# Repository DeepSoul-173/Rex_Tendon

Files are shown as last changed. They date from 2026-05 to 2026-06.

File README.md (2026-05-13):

# Rex Tendon
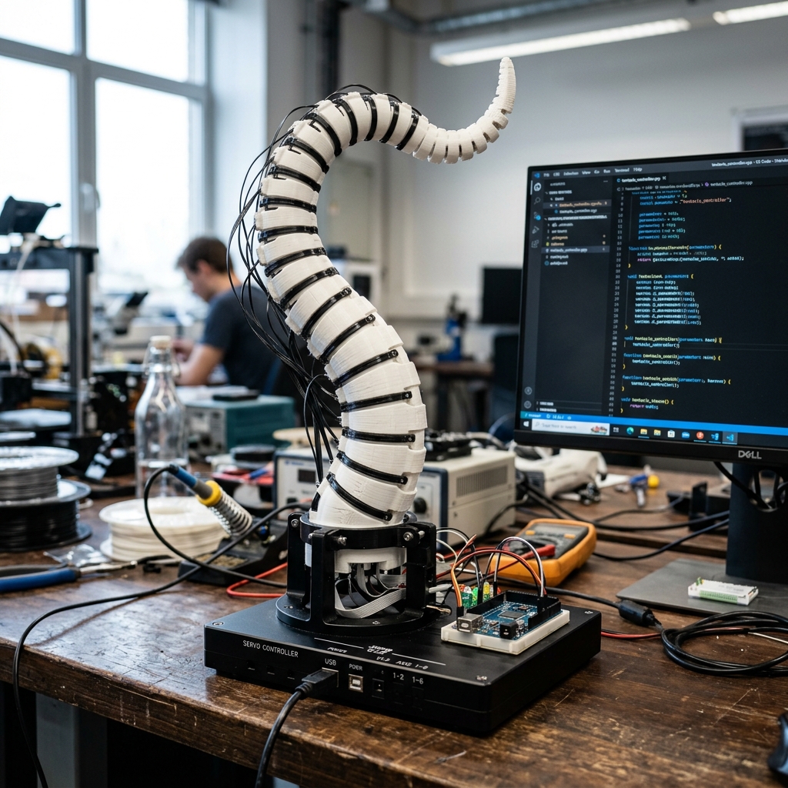
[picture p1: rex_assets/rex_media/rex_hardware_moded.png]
Rex Tendon Hardware


Rex Tendon is a soft-bodied tentacle robot using the [SpiRobs](https://arxiv.org/pdf/2303.09861) design, controlled through a mix of reinforcement learning and GPT-4o. Read the full blogpost [here](https://www.matthieulc.com/posts/rex-tendon/).

## Quick Start

### 1. Installation

First, ensure you have Python 3.10+ and [Poetry](https://python-poetry.org/docs/#installation) installed.

Clone the project repository and install the dependencies:
```bash
git clone https://github.com/DeepSoul-173/Rex_Tendon
cd rex-tendon
poetry install
```

Next, `lerobot` is a key dependency that needs to be installed from source:
```bash
git clone https://github.com/huggingface/lerobot.git
pip install -e ./lerobot
```

Finally, activate the virtual environment to run the subsequent commands:
```bash
eval "$(poetry env activate)"
```

### 2. Hardware Configuration

Find the USB port for the driver board using a script from `lerobot`:
```bash
python lerobot/scripts/find_motors_bus_port.py
```

Once you have the port, configure each motor (for IDs 1, 2, and 3), replacing `DRIVER_BOARD_USB_PORT` with the port you found:
```bash
python lerobot/scripts/configure_motor.py \
  --port DRIVER_BOARD_USB_PORT \
  --brand feetech \
  --model sts3215 \
  --baudrate 1000000 \
  --ID 1
```

### 3. Motor Calibration

Calibrate the motors by adjusting with the arrow keys until the tentacle tip is straight, then press Enter to save:
```bash
python -m rex_tendon calibrate --config rex_tendon/configs/default_hardware.yaml
```

### 4. Run the Orchestrator

Run the main orchestrator application, which integrates all system components:
```bash
python -m rex_tendon orchestrate \
  --config rex_tendon/configs/default_orchestrator.yaml \
  --hardware-config rex_tendon/configs/default_hardware.yaml \
  --perception-config rex_tendon/configs/default_perception.yaml \
  --control-config rex_tendon/configs/default_control.yaml
```

## Hardware Replication

For a full replication and setup of the robot, follow the steps in [ASSEMBLY.md](ASSEMBLY.md). All 3D printing assets are included in the repository. The total should cost less than 200$.

## Software Replication

### 1. Hardware Setup

Test motor connections:
```bash
python -m rex_tendon primitive "<yes>" --config rex_tendon/configs/default_hardware.yaml
```

Calibrate motors:
```bash
python -m rex_tendon calibrate --config rex_tendon/configs/default_hardware.yaml
```

### 2. Manual Control

Control with trackpad:
```bash
python -m rex_tendon trackpad --config rex_tendon/configs/default_hardware.yaml
```

Test idle motion with breathing pattern:
```bash
python -m rex_tendon idle --duration 10 \
  --hardware-config rex_tendon/configs/default_hardware.yaml \
  --control-config rex_tendon/configs/default_control.yaml
```

### 3. RL Pipeline

Generate MuJoCo XML model:
```bash
python -m rex_tendon generate-xml --output-path rex_assets/rex_simulation/tentacle.xml
```

Train RL model:
```bash
python -m rex_tendon rl train --config rex_tendon/configs/default_rl_training.yaml
```

Monitor with Tensorboard:
```bash
tensorboard --logdir=./
```

Evaluate RL model in simulation:
```bash
mjpython -m rex_tendon rl evaluate ./rex_results/ppo_tentacle_XXXXXXX/rex_models/best_model.zip --config rex_tendon/configs/default_rl_training.yaml --num-episodes 10 --render
```

### 4. Vision Pipeline

Record calibration images for stereo triangulation. Tune the pause interval to have time to change the pattern orientation:
```bash
python -m rex_tendon record stereo-calibration --num-pairs 20 --interval 3
```

Calculate the stereo triangulation calibration parameters using the images you just recorded by following the steps in the DeepLabCut notebook under `notebooks/3d_triangulation.ipynb`.

Record annotation videos. This command will record 6 pairs (one for each camera) of 10 second videos:
```bash
python -m rex_tendon record annotation --duration 60 --chunk-duration 10
```

Extract representative frames using k-means:
```bash
python -m rex_tendon extract-frames video.mp4 output_frames/ 100
```

I used [roboflow](https://roboflow.com/) to annotate these images, it has a great auto-label feature to avoid wasting time on high confidence images.

Then change `base_model` in the vision training config to point to the best model checkpoint and continue training on real images.

Evaluate trained model:
```bash
python -m rex_tendon vision evaluate model.pt dataset.yaml --config rex_tendon/configs/default_vision_training.yaml
```

Infer on single image:
```bash
python -m rex_tendon vision predict model.pt image.jpg --output prediction.jpg --confidence 0.5 --config rex_tendon/configs/default_vision_training.yaml
```

Debug stereo vision and triangulation:
```bash
python -m rex_tendon debug-perception --config rex_tendon/configs/default_perception.yaml
```

### 5. Full System

Run the closed loop RL model and vision model on the real robot:
```bash
python -m rex_tendon.control.closed_loop \
  --control-config rex_tendon/configs/default_control.yaml \
  --perception-config rex_tendon/configs/default_perception.yaml \
  --hardware-config rex_tendon/configs/default_hardware.yaml
```

Run the full orchestrator:
```bash
python -m rex_tendon orchestrate \
  --config rex_tendon/configs/default_orchestrator.yaml \
  --hardware-config rex_tendon/configs/default_hardware.yaml \
  --perception-config rex_tendon/configs/default_perception.yaml \
  --control-config rex_tendon/configs/default_control.yaml
```

## Known Issues

- Control can sometimes cause the motors to go into infinite rolling/unrolling for unknown reasons. What works for me in the situation is to reset by unrolling the cables to their maximum, and re-rolling them back. This sometimes requires opening up the robot to untangle wires. I haven't found the time to fix this, if you do, please open a PR!
- `orchestrator/orchestrator.py`, `control/closed_loop.py` and `control/idle.py` were heavily vibe-coded and have only been lightly refactored.
- Inference using `control/closed_loop.py` leads to a tracking offset on the Y axis as compared to simulation.

## Possible Extensions

- Increase robustness of GPT4o layer or train from scratch (e.g. [Moshi-like](https://kyutai.org/rex_assets/pdfs/Moshi.pdf))
- Give it a voice (but as non-human as possible!)
- Train more RL policies (e.g. grabbing and holding complex objects)
- Use direct drive motors to reduce noise
- Add more tentacles and make it crawl
- Ditch the 2D projection control to unlock more expressive policies

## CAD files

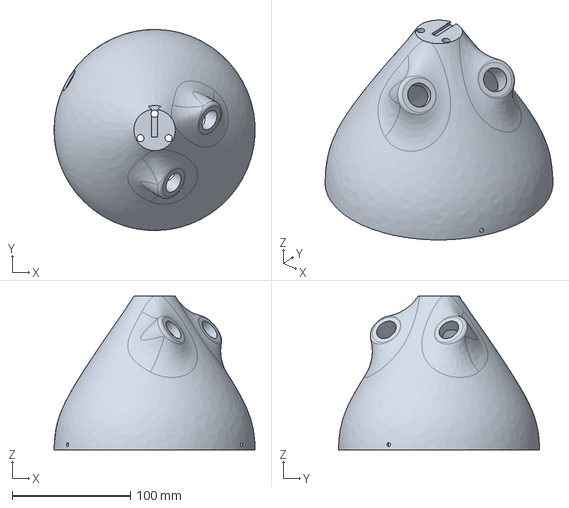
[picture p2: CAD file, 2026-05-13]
rex_assets/rex_hardware/printing/dome.step
169.9 x 169.9 x 130.0 mm

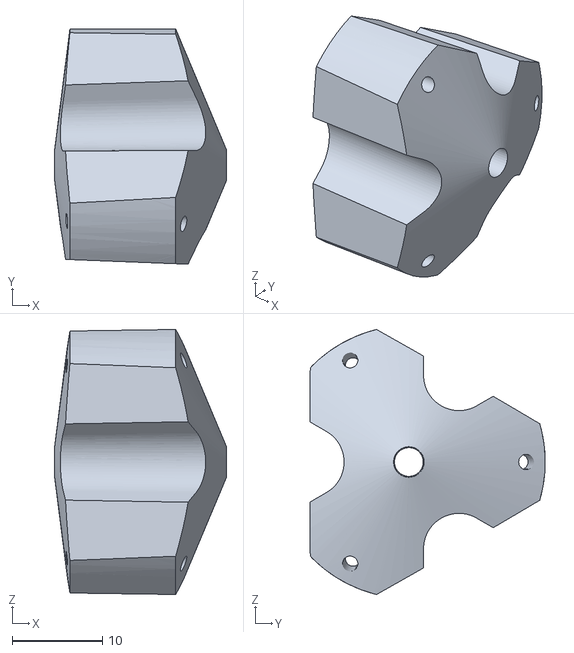
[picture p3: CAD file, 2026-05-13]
rex_assets/rex_simulation/mujoco_rex_assets/Part2.stl
19.1 x 26.1 x 29.3

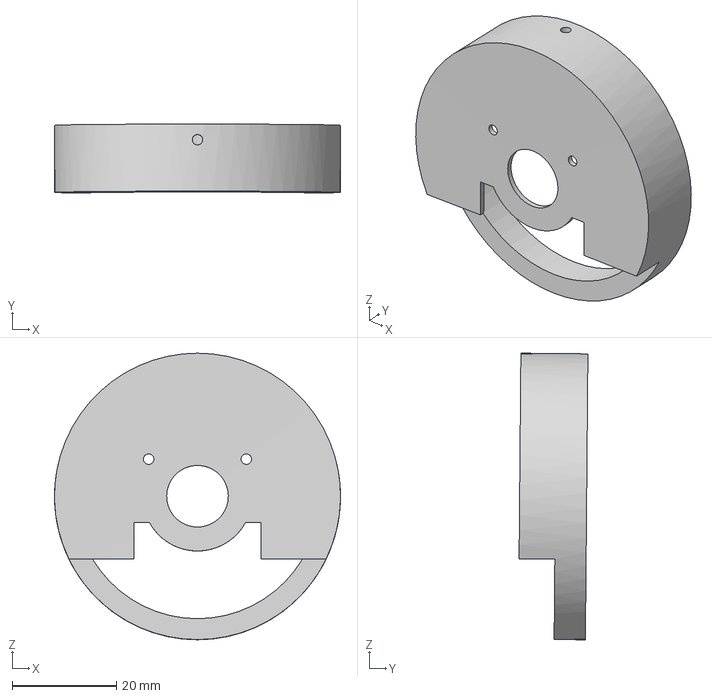
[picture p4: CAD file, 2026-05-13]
rex_assets/rex_hardware/printing/roller_cover.step
54.8 x 13.2 x 54.9 mm

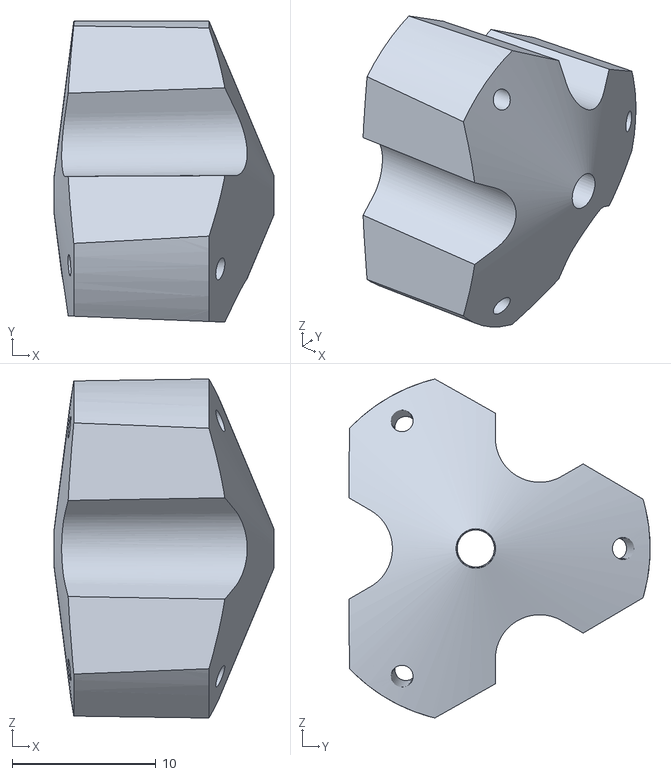
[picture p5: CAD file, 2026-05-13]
rex_assets/rex_simulation/mujoco_rex_assets/Part5.stl
15.3 x 20.9 x 23.6

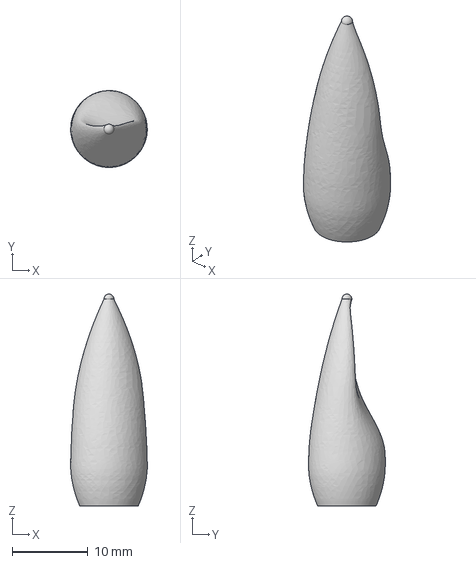
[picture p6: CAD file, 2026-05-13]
rex_assets/rex_hardware/printing/spike.step
10.1 x 10.1 x 27.9 mm

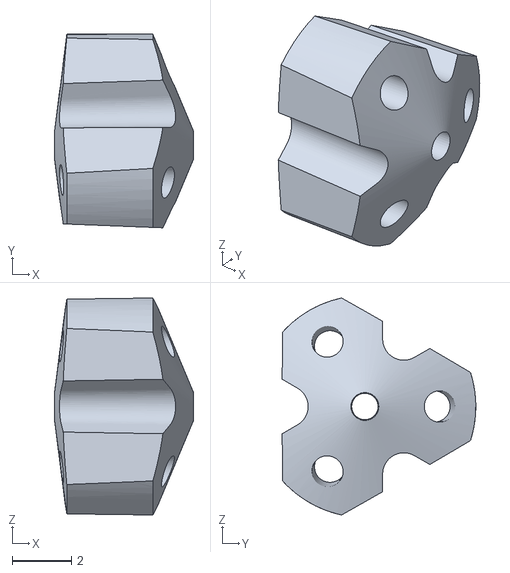
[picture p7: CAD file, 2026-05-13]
rex_assets/rex_simulation/mujoco_rex_assets/Part21.stl
4.70 x 6.55 x 7.33

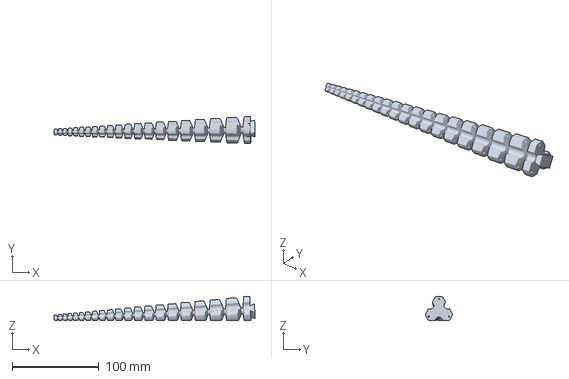
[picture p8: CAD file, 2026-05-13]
rex_assets/rex_hardware/printing/thick_spirobs.3mf
231.5 x 31.4 x 27.8 mm

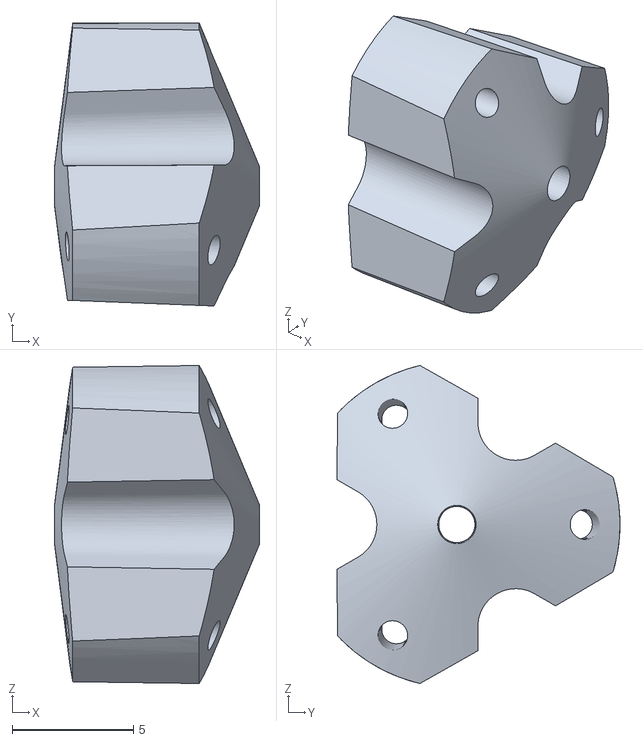
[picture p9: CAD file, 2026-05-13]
rex_assets/rex_simulation/mujoco_rex_assets/Part13.stl
8.49 x 11.7 x 13.1

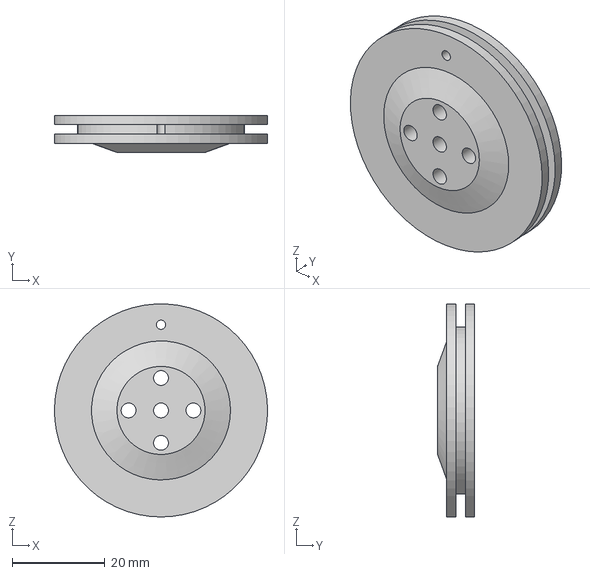
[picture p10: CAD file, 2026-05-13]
rex_assets/rex_hardware/printing/roller.step
46.0 x 8.00 x 46.0 mm

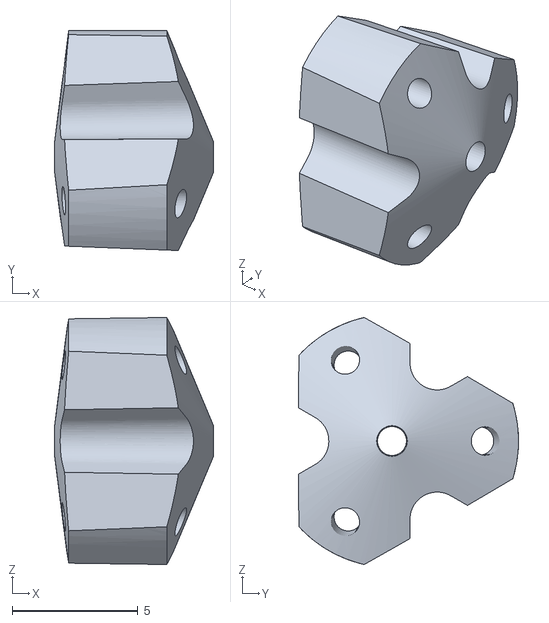
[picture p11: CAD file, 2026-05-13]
rex_assets/rex_simulation/mujoco_rex_assets/Part17.stl
6.32 x 8.74 x 9.81

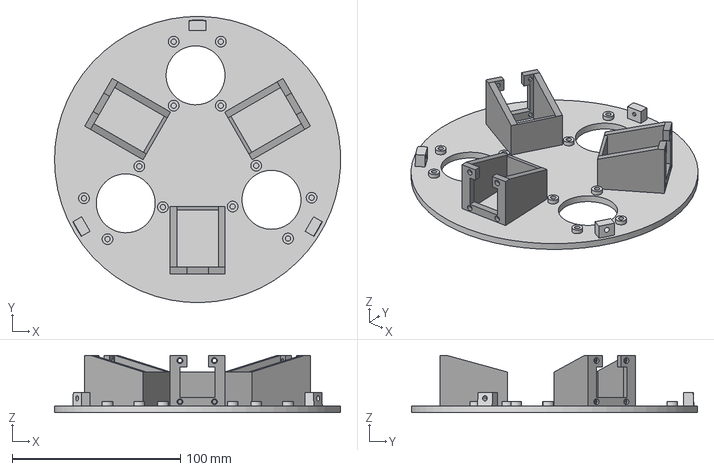
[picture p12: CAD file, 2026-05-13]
rex_assets/rex_hardware/printing/plate.step
169.9 x 169.9 x 34.0 mm

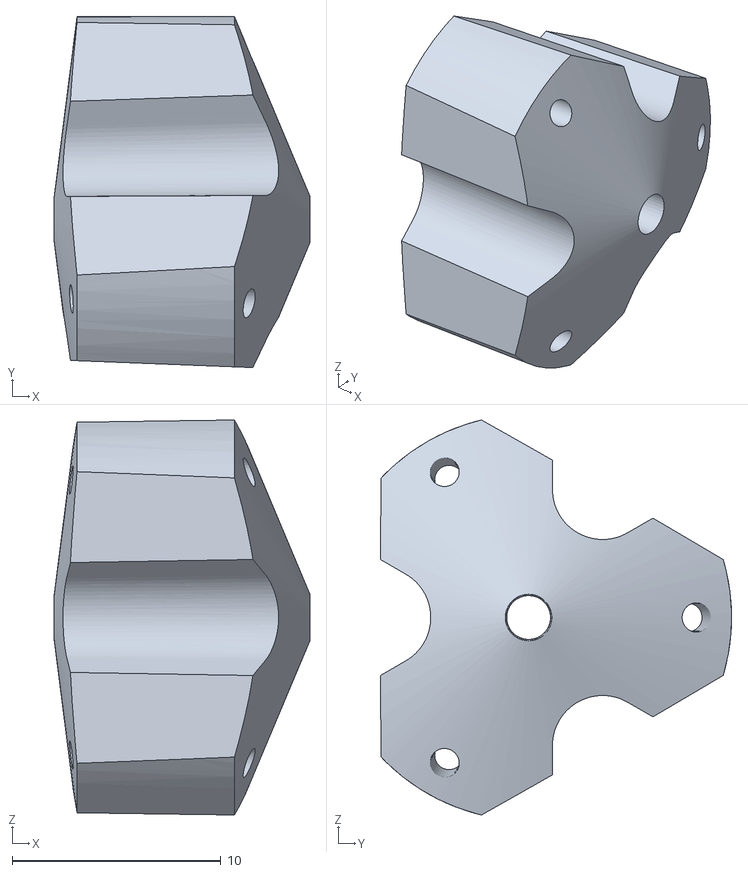
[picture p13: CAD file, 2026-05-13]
rex_assets/rex_simulation/mujoco_rex_assets/Part8.stl
12.3 x 16.8 x 18.9

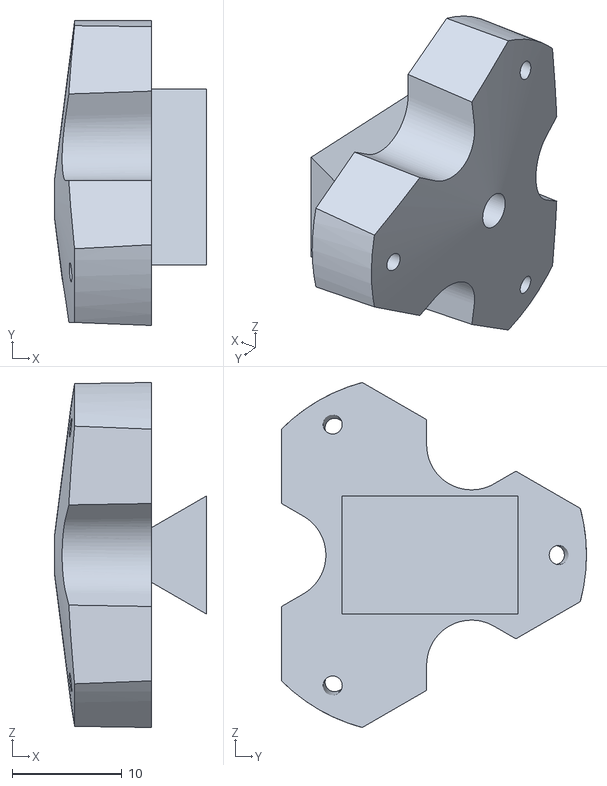
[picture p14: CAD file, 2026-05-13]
rex_assets/rex_simulation/mujoco_rex_assets/Part1.stl
13.9 x 27.8 x 31.4

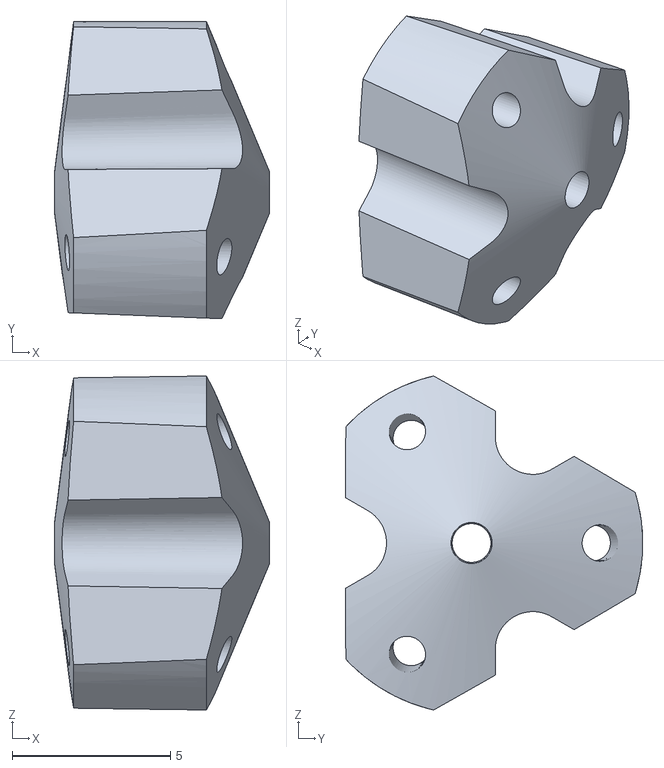
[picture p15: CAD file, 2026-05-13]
rex_assets/rex_simulation/mujoco_rex_assets/Part16.stl
6.80 x 9.40 x 10.6

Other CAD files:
rex_assets/rex_simulation/mujoco_rex_assets/Part9.stl
rex_assets/rex_simulation/mujoco_rex_assets/Part3.stl
rex_assets/rex_simulation/mujoco_rex_assets/Part11.stl
rex_assets/rex_simulation/mujoco_rex_assets/Part12.stl
rex_assets/rex_simulation/mujoco_rex_assets/Part10.stl
rex_assets/rex_simulation/mujoco_rex_assets/Part14.stl
rex_assets/rex_simulation/mujoco_rex_assets/Part15.stl
rex_assets/rex_simulation/mujoco_rex_assets/Part18.stl
rex_assets/rex_simulation/mujoco_rex_assets/Part19.stl
rex_assets/rex_simulation/mujoco_rex_assets/Part20.stl
rex_assets/rex_simulation/mujoco_rex_assets/Part4.stl
rex_assets/rex_simulation/mujoco_rex_assets/Part6.stl
rex_assets/rex_simulation/mujoco_rex_assets/Part7.stl

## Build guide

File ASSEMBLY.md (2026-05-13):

# Assembly

## Parts List

### Electronics
- **1x** Waveshare Serial Bus Servo Driver Board  
  [Amazon](https://www.amazon.fr/dp/B0CJ6TP3TP)

- **3x** Waveshare 20kg.cm Bus Servo Motors (includes mounting screws)
  [Amazon](https://www.amazon.fr/dp/B0CDC587BQ)

- **1x** 60W 12V 5A Power Supply  
  [Amazon](https://www.amazon.fr/dp/B001W3UYLY)

- **1x** USB-C to USB-C cable (for servo driver board)
- **1x** USB Micro to USB-C cable (for camera)

- **1x** Synchronous 3D Stereo USB Camera (3840×1080P, 4MP, 60fps, 130° FOV)  
  [AliExpress](https://www.aliexpress.com/item/1005006353765708.html)

> **Note:** If using a different camera, you may need to adapt the 3D printed parts and object detection model accordingly.

### Hardware
- **2x** M2×3×3 Heat Set Inserts  
  [Amazon](https://www.amazon.fr/dp/B0CS6XJSSL)

- **7x** M2.5×3.5×4 Heat Set Inserts  
  [Amazon](https://www.amazon.fr/dp/B0CS6YVJYD)

- **2x** M2 × 6mm Screws

- **2x** M2.5 × 10mm Screws

- **3x** M2.5 × 6mm Screws

- **0.5mm 21kg Fishing Wire** (we'll later cut 3x 80cm segments)

### 3D Printing Materials
- **eTPU-95A Filament** (for printing SpiRobs)  
  [eSUN 3D](https://esun3d.fr/products/esun-etpu-95a-gris-grey-1-75-mm-1-kg)

- **PLA Filament** (for rigid structural parts)

## Printing

### Dome - PLA
<div align="center">
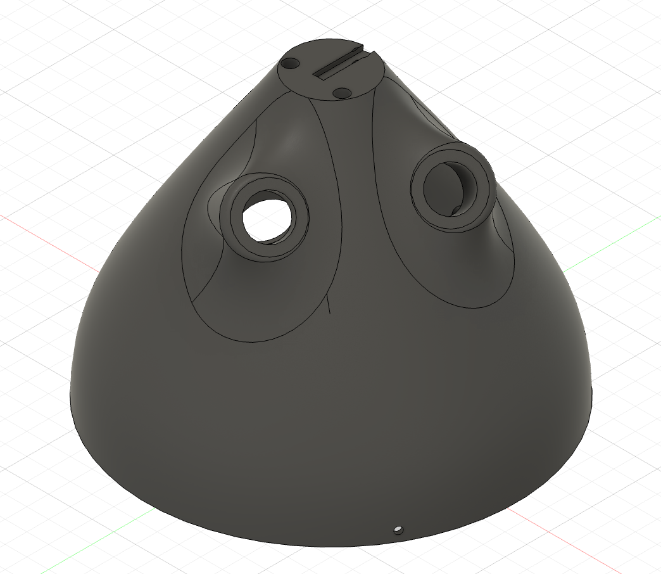
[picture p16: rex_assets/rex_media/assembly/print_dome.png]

</div>

[Download STEP file](rex_assets/rex_hardware/printing/dome.step)

### Plate - PLA
<div align="center">
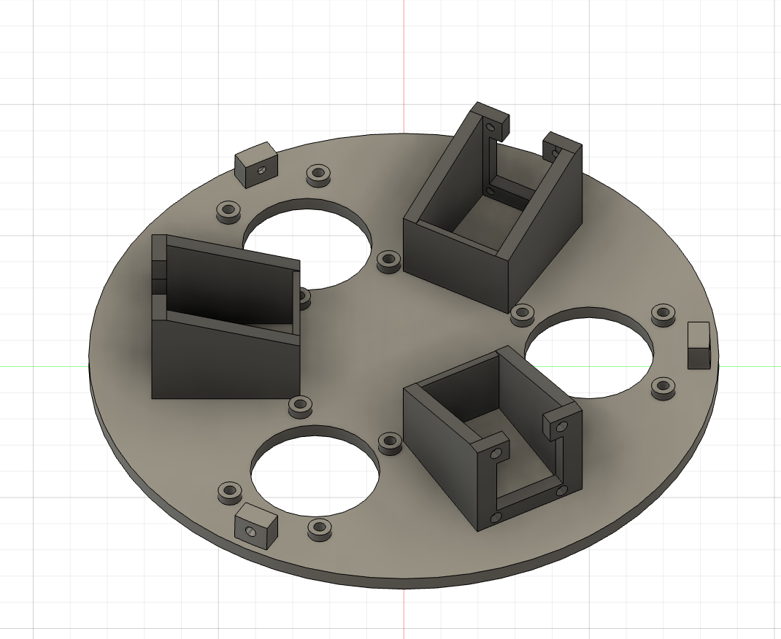
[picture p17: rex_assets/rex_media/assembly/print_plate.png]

</div>

[Download STEP file](rex_assets/rex_hardware/printing/plate.step)

### Roller Cover - PLA (3x)
<div align="center">
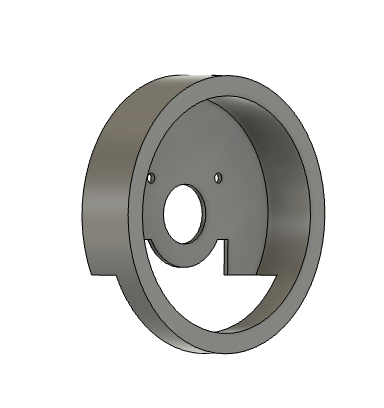
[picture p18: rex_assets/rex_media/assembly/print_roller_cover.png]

</div>

[Download STEP file](rex_assets/rex_hardware/printing/roller_cover.step)

### Roller - PLA (3x)
<div align="center">
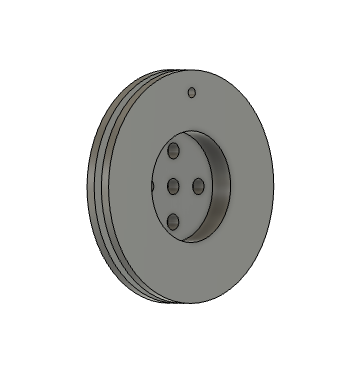
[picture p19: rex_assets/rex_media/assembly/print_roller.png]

</div>

[Download STEP file](rex_assets/rex_hardware/printing/roller.step)

### Spike - PLA
<div align="center">
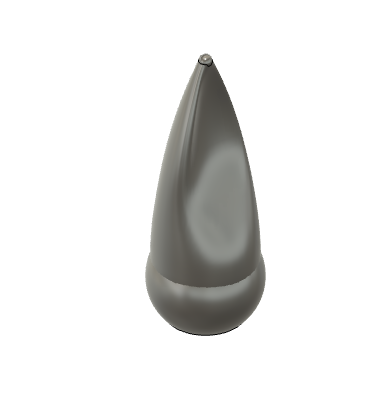
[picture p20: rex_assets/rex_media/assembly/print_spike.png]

</div>

[Download STEP file](rex_assets/rex_hardware/printing/spike.step)

### Thick SpiRobs - eTPU
<div align="center">
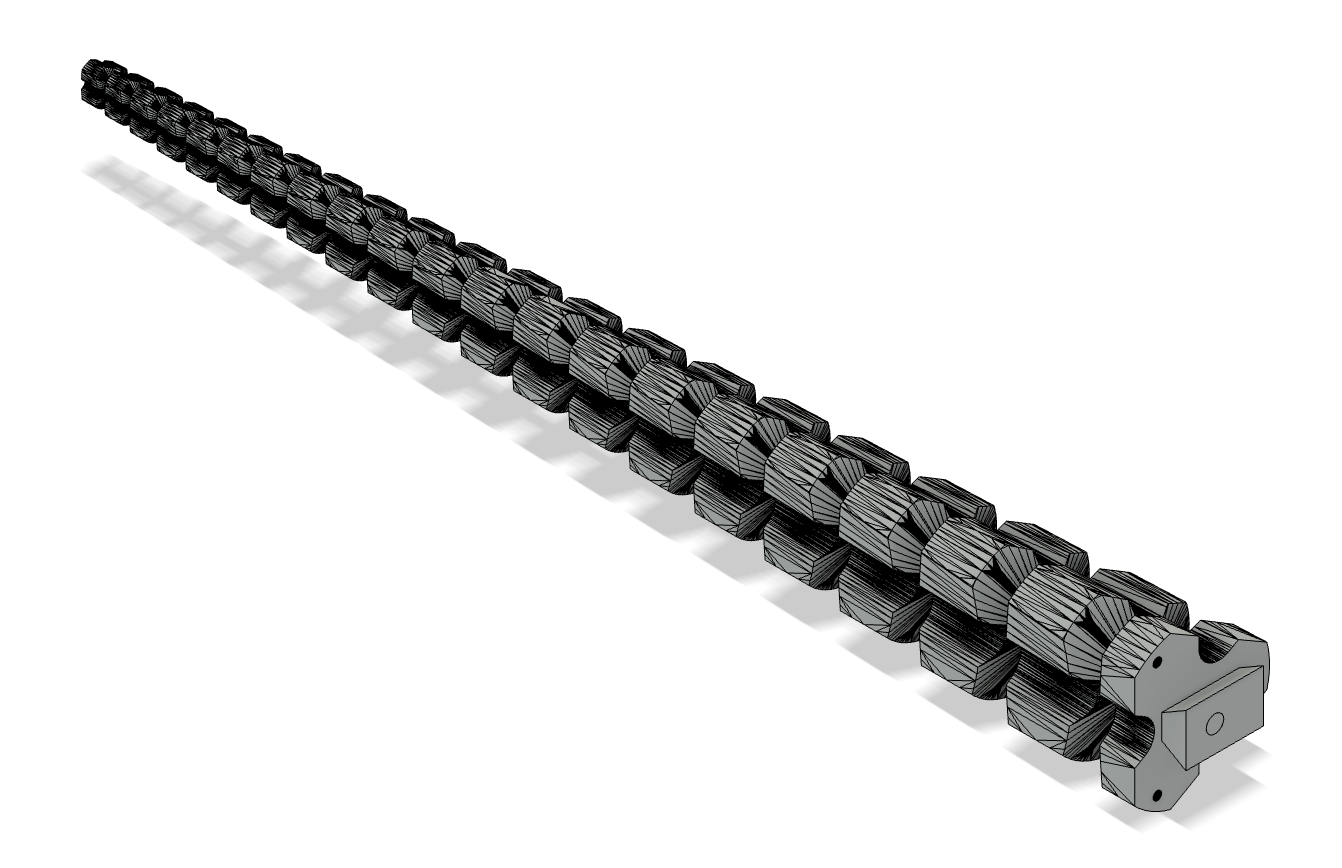
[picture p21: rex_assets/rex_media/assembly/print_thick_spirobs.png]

</div>

[Download 3MF file](rex_assets/rex_hardware/printing/thick_spirobs.3mf) | [Download STEP file](rex_assets/rex_hardware/printing/thick_spirobs.step)

> **Note:** This is a modified version of the 3-cable SpiRobs with a thicker spine for increased rigidity and stability.

## Assembly Instructions

### Plate Preparation and Servo Driver Board Installation

Install 4x M2.5 heat set inserts at either of the driver board mounting locations on the plate using a soldering iron.

<div align="center">
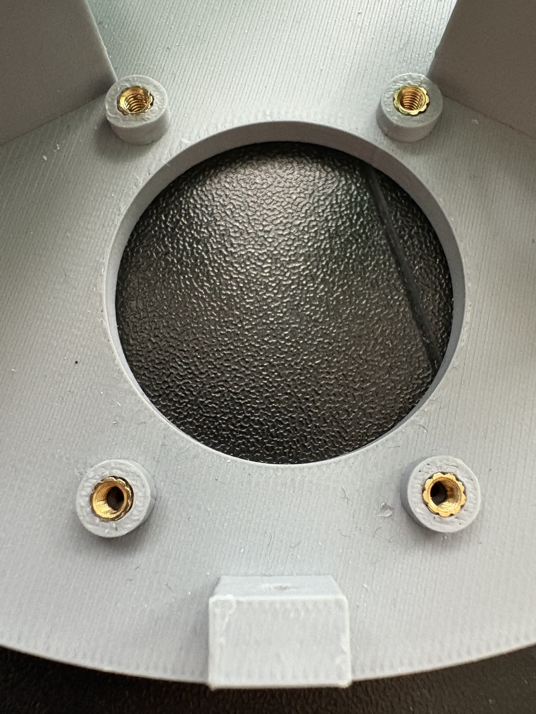
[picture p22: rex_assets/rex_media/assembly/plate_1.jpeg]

</div>

Install 3x M2.5 heat set inserts at the dome fastener locations using a soldering iron.

<div align="center">
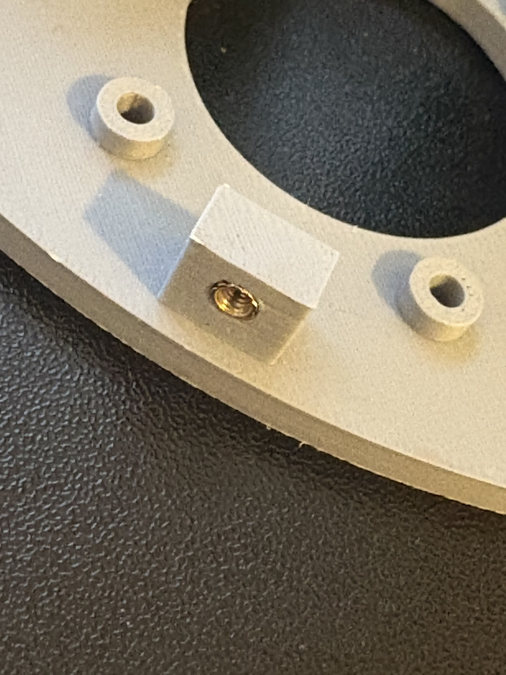
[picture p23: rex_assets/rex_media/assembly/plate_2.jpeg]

</div>

Mount the servo driver board to the plate using 2x M2.5 × 10mm screws (alternatively, use all four corner mounting holes). PCB standoffs can be used to elevate the driver board if desired.

<div align="center">
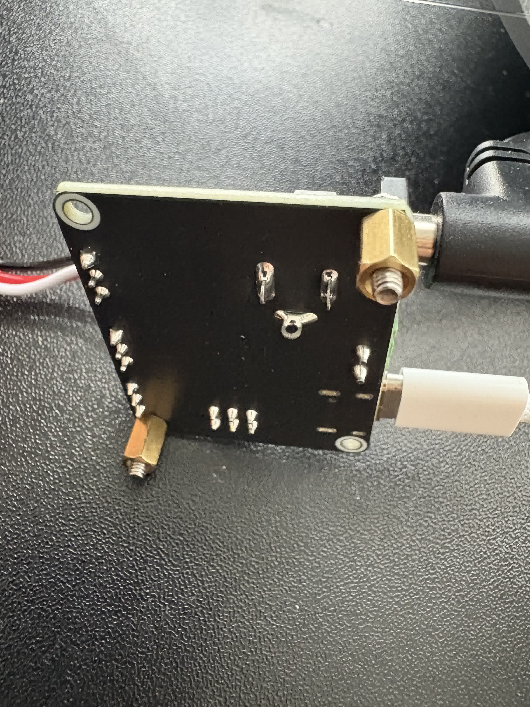
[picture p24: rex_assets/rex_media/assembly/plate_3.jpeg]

</div>

Secure the board to the plate at the previously installed insert locations.

<div align="center">
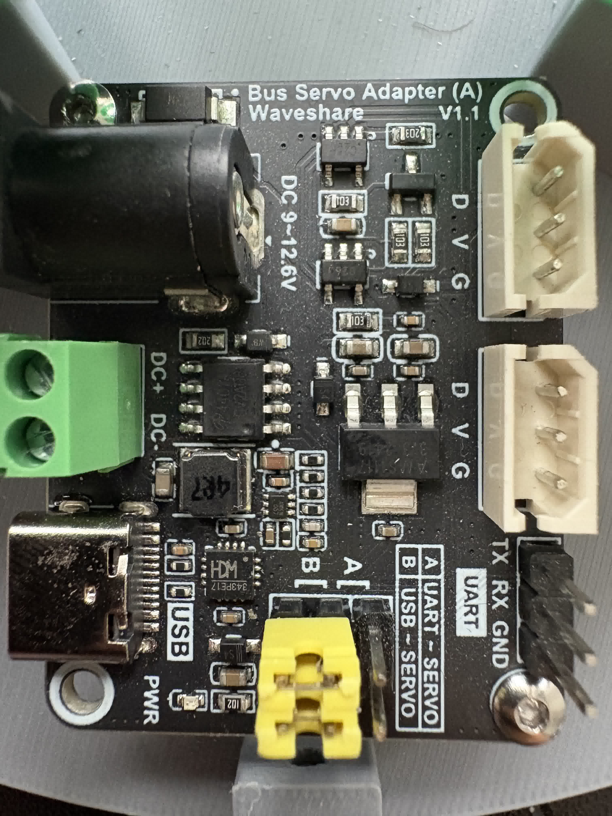
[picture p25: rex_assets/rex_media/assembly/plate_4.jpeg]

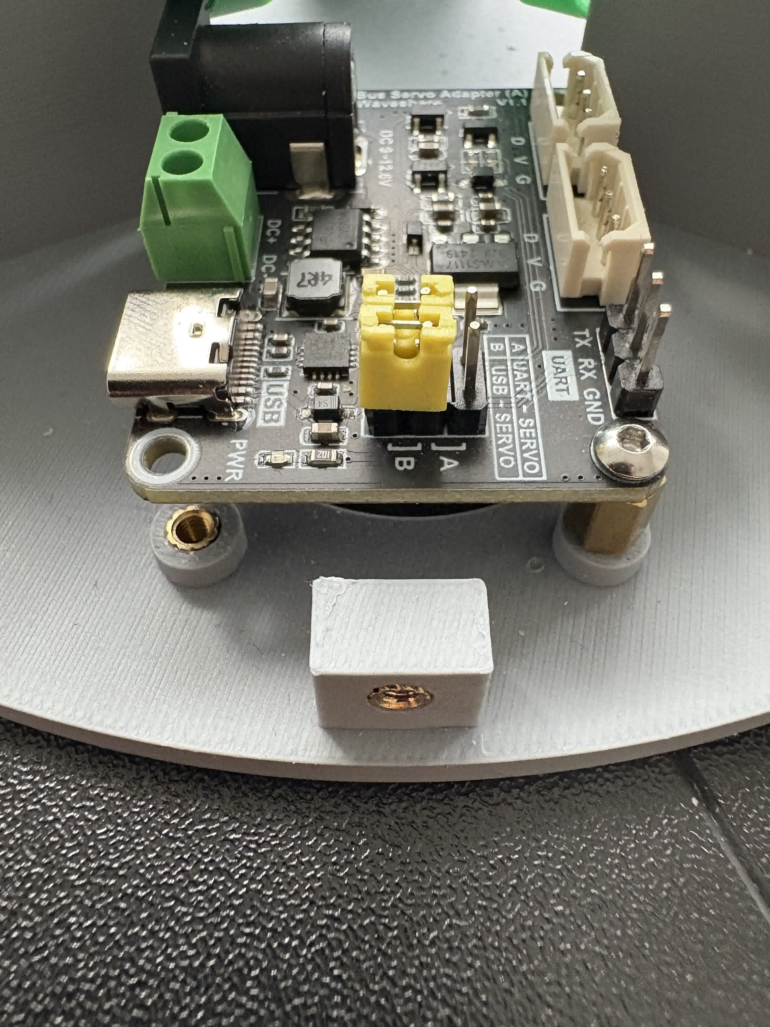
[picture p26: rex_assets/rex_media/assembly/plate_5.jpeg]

</div>

### Camera Mounting

Install 2x M2 heat set inserts at the camera fastener locations on the dome using a soldering iron.

<div align="center">
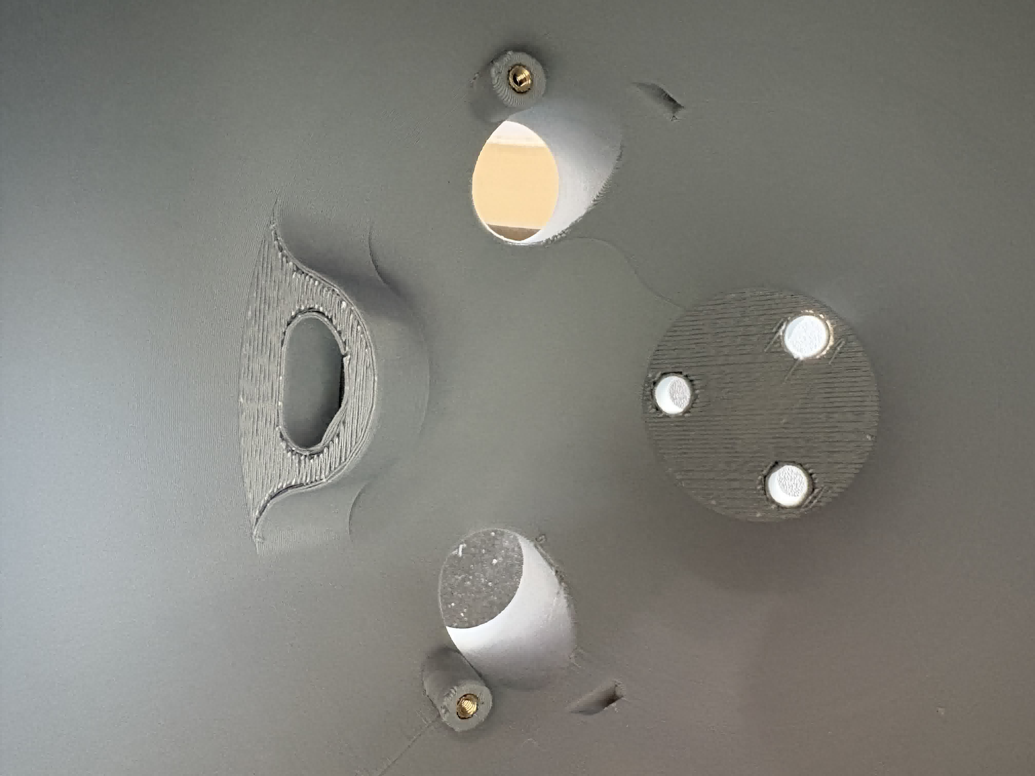
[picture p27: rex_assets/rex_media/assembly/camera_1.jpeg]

</div>

Position the camera in the mounting recesses within the dome and secure with 2x M2 × 6mm screws into the installed inserts.

<div align="center">
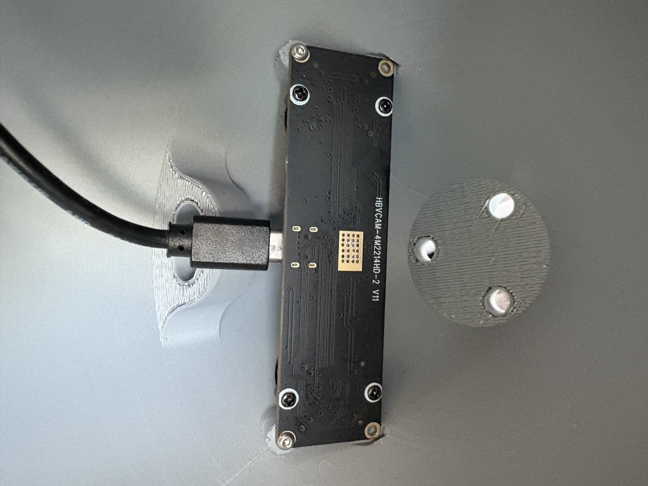
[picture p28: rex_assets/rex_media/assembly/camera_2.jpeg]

</div>

### Motor Assembly and Mounting

Remove the two top screws from each Waveshare motor and insert the motors into the roller covers.

<div align="center">
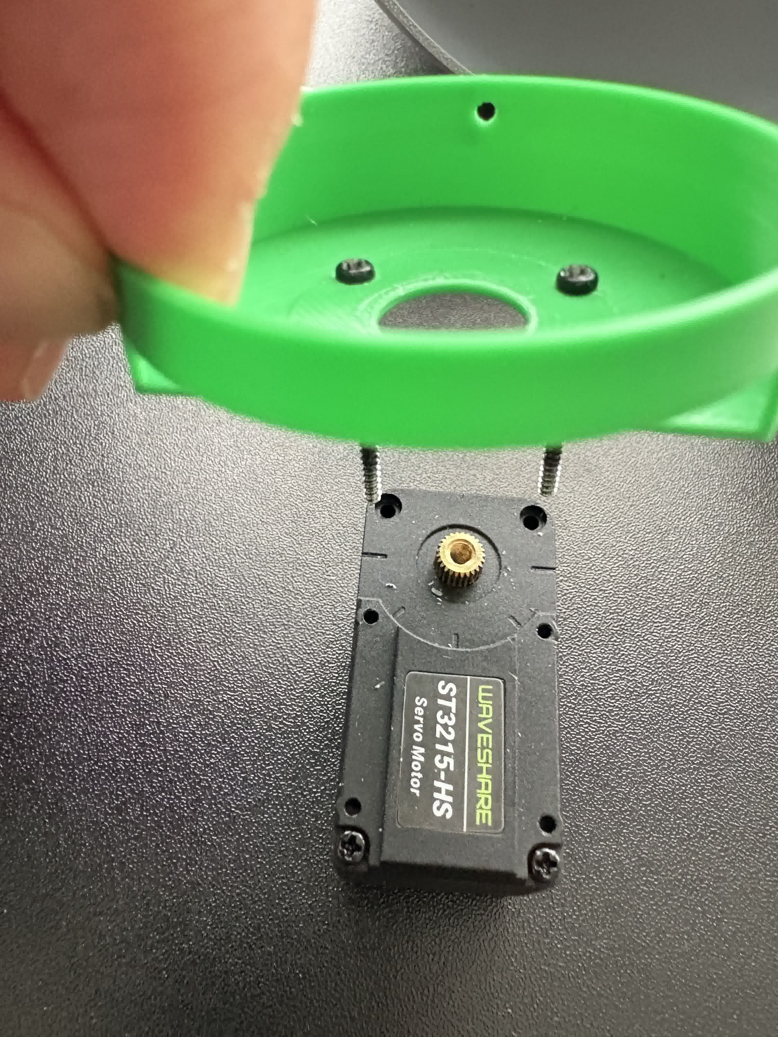
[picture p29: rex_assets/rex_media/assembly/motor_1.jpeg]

</div>

Reinstall the screws to secure the motors within the roller covers.

<div align="center">
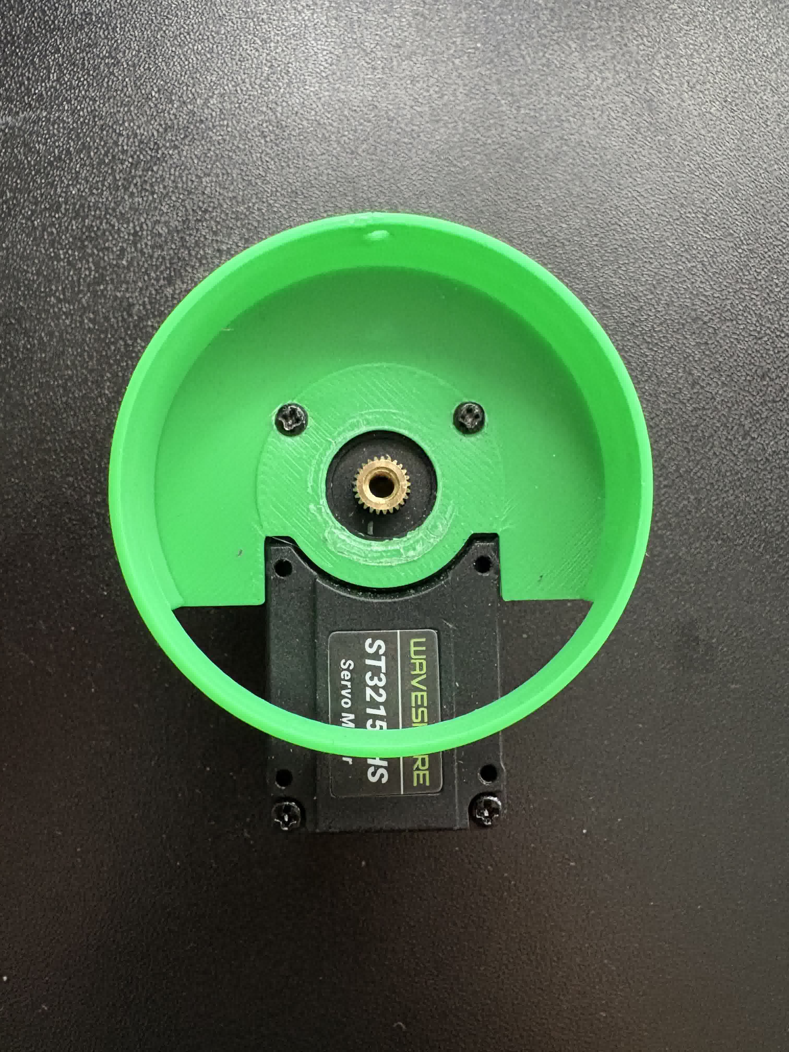
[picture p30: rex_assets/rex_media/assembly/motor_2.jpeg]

</div>

Attach the rollers to each motor assembly.

<div align="center">
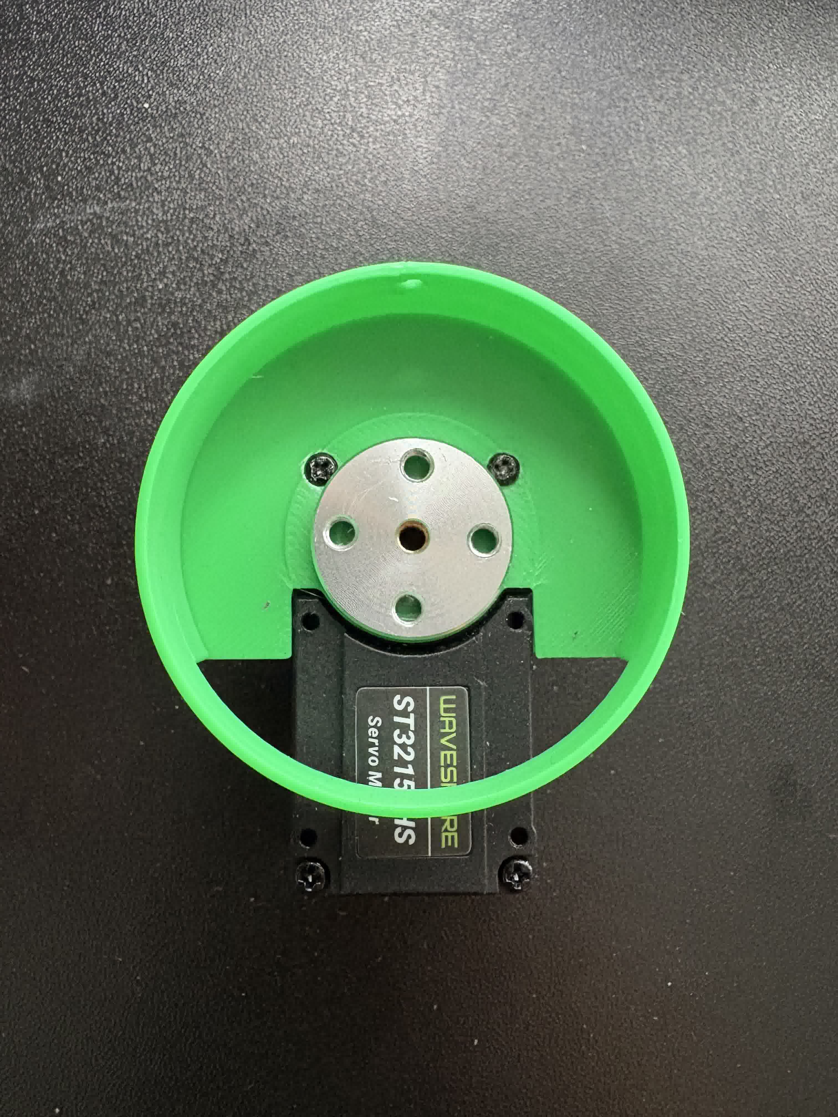
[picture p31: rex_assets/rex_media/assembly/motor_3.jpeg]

</div>

Repeat this procedure for the two other servo motors. Before proceeding, assign motor IDs according to the diagram below. Use stickers to identify each motor. For proper operation with the control software, each motor must be assigned the correct ID relative to the driver board position. The driver board should be positioned near the cable opening, opposite the camera where most operations will occur.

To assign motor IDs using the LeRobot codebase:

1. Connect each motor individually to the driver board
2. Connect the power cable to the driver board and USB-C cable to your computer
3. Find the USB port for the driver board:
```bash
git clone https://github.com/huggingface/lerobot.git
cd lerobot
python lerobot/scripts/find_motors_bus_port.py
```

4. Configure each motor ID (repeat for motors 1, 2, and 3):
```bash
python lerobot/scripts/configure_motor.py \
  --port DRIVER_BOARD_USB_PORT \
  --brand feetech \
  --model sts3215 \
  --baudrate 1000000 \
  --ID 1
```

Once configured, insert each motor into its designated slot on the plate.

<div align="center">
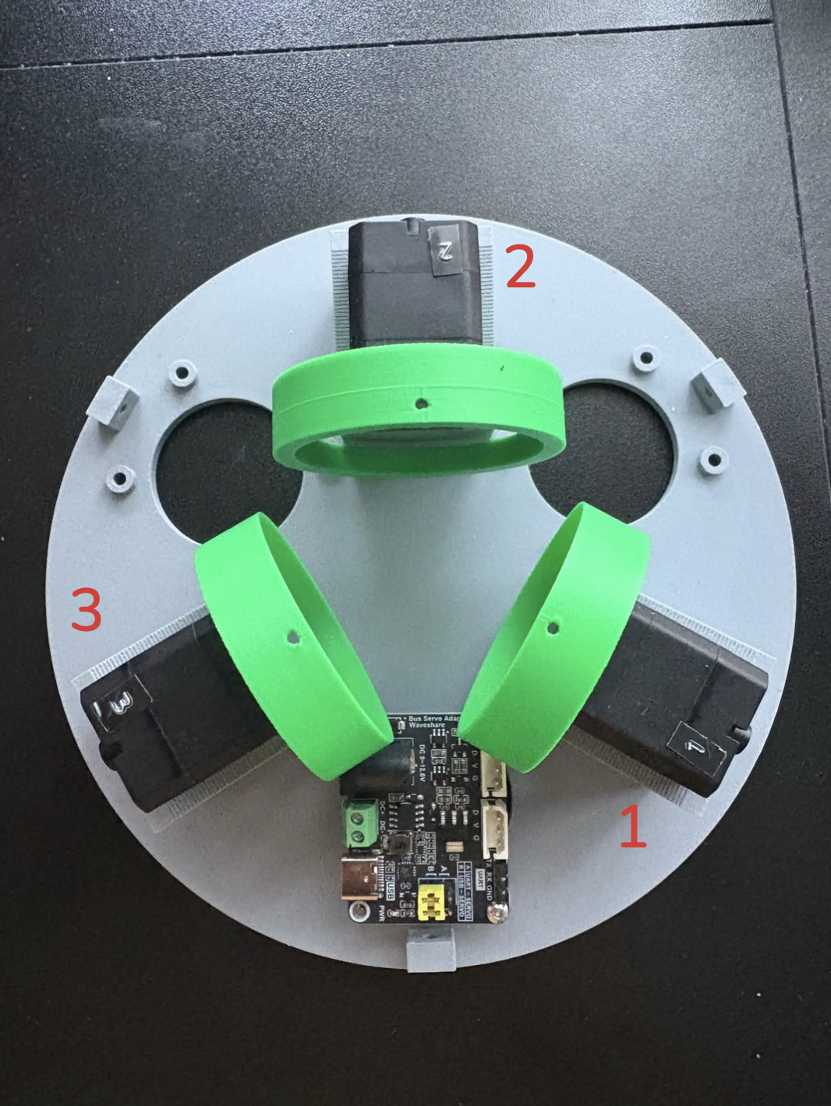
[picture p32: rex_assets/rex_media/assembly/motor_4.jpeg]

</div>

Secure the motors to the plate using the screws provided with the Waveshare motors (2 screws per motor recommended).

<div align="center">
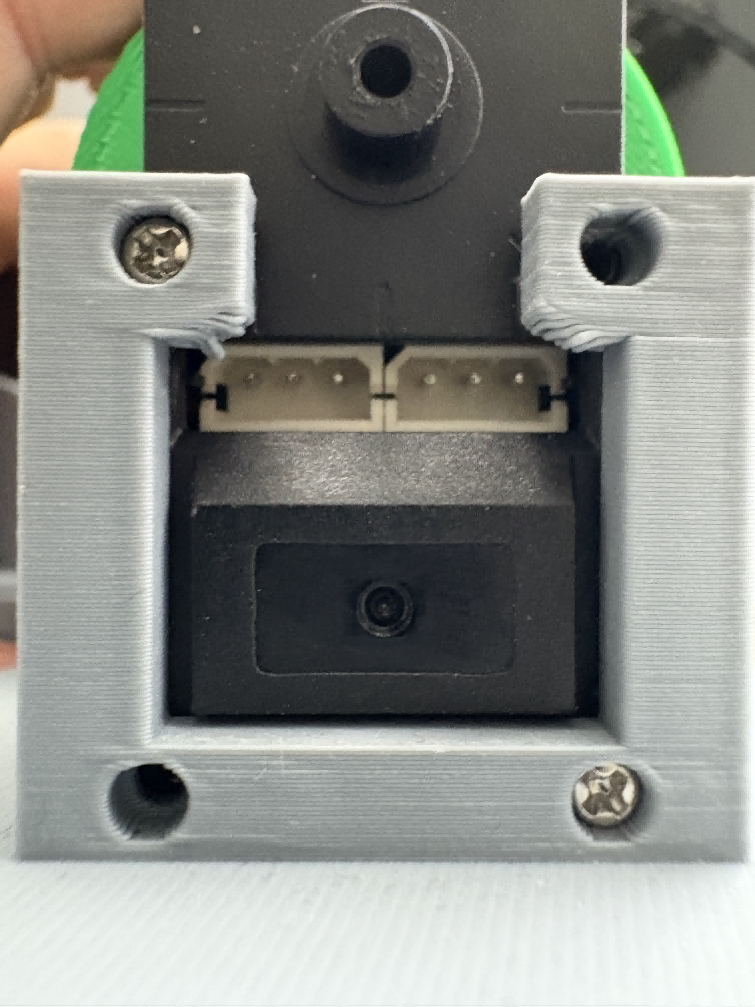
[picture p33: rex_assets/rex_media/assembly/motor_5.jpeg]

</div>

The assembly should now appear as shown below.

<div align="center">
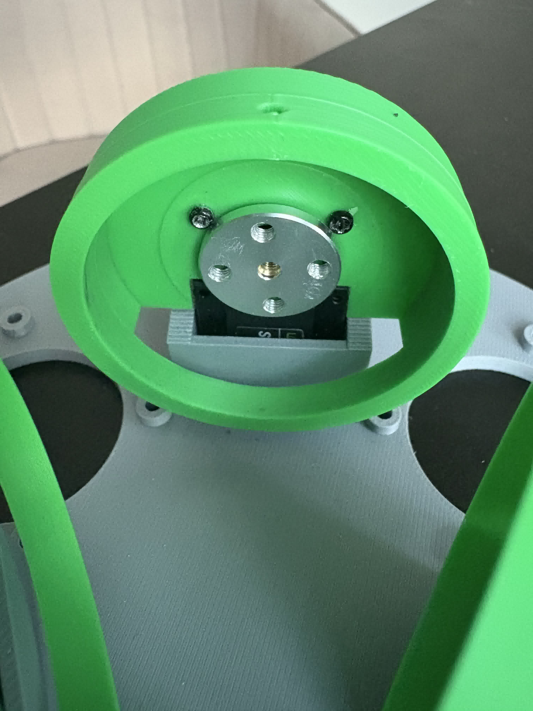
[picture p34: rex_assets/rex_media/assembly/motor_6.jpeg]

</div>

Install the fishing wire rollers. Begin by partially threading one screw into the roller to help with positioning on the wheel. A magnetic screwdriver is particularly useful for this step.

<div align="center">
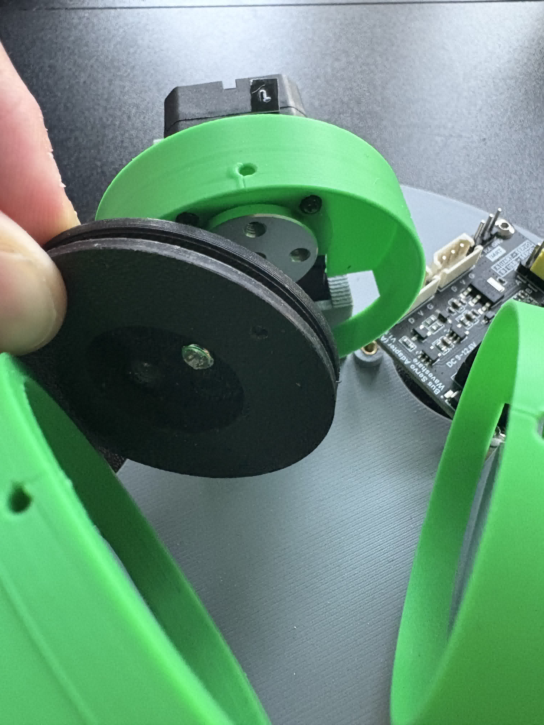
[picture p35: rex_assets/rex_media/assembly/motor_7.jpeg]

</div>

Fully secure the roller to the wheel.

<div align="center">
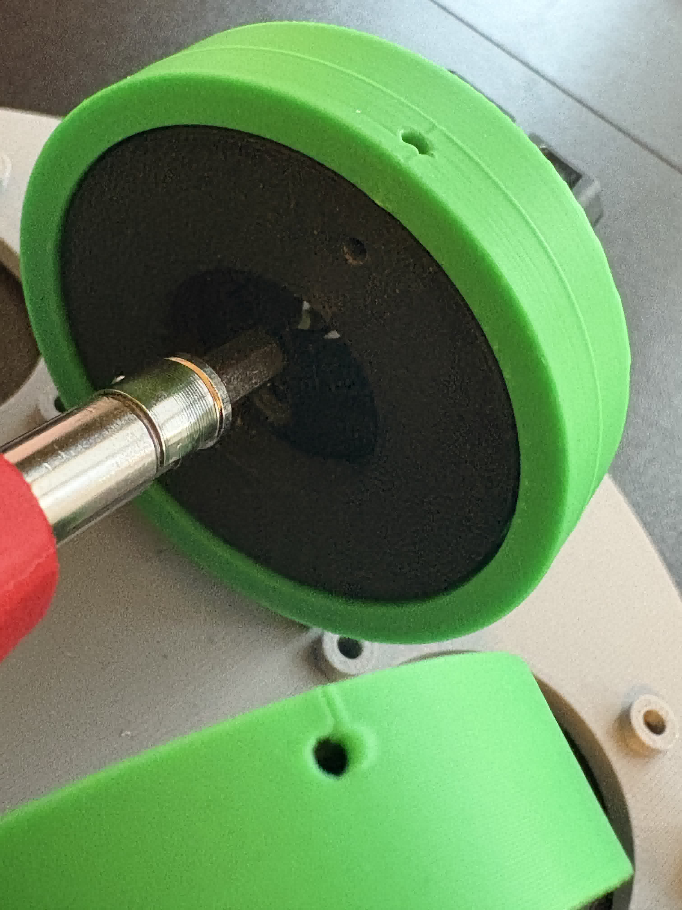
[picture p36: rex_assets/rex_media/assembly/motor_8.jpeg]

</div>

Ensure proper alignment:
- The remaining roller screw holes align with the wheel screw holes
- The fishing wire through-hole in the roller aligns with the through-hole in the roller cover

Use the screwdriver to rotate the motor/roller assembly as needed for proper alignment.

<div align="center">
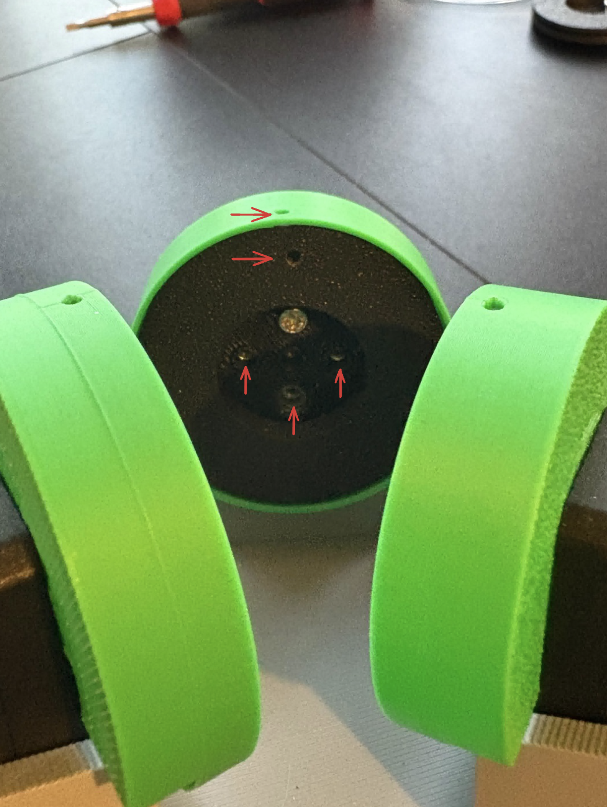
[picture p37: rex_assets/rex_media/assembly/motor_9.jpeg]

</div>

Install the fishing wires (this is one of the most challenging step). Create a small bend at one end of each 80cm wire to facilitate insertion.

<div align="center">
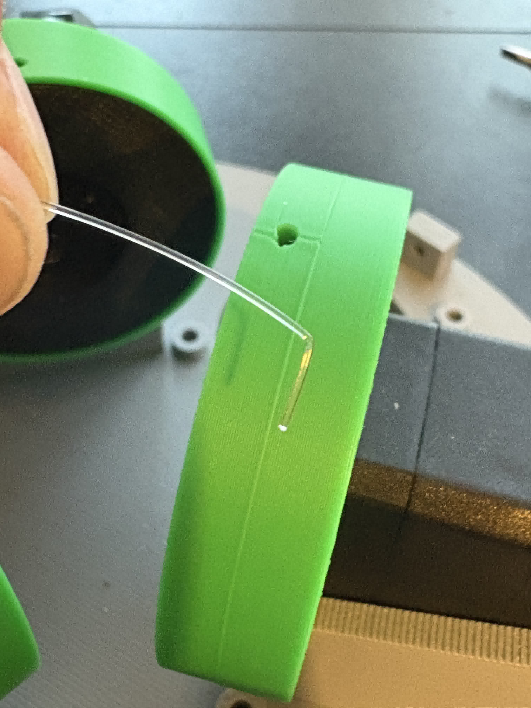
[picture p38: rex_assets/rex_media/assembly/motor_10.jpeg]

</div>

Thread the wire through both aligned holes.

<div align="center">
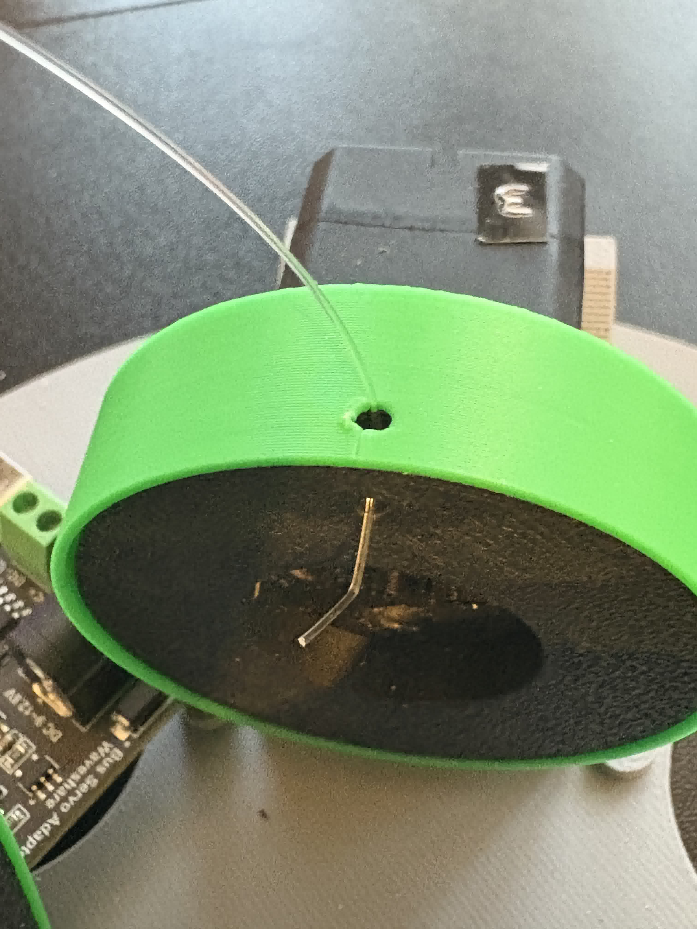
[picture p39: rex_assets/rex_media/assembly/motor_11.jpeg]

</div>

Bend the wire and insert it into the lower screw hole of the roller, opposite the already-installed screw.

<div align="center">
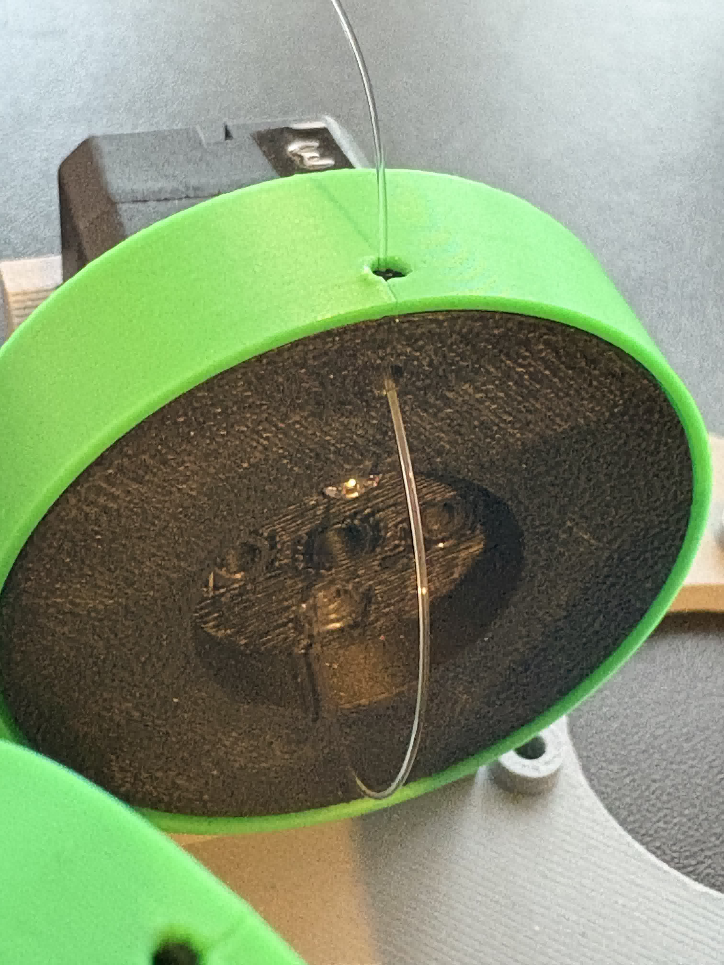
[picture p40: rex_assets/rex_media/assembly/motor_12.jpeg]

</div>

Install another Waveshare motor screw to secure the wire. Ensure the screw fully engages with the motor wheel threads.

<div align="center">
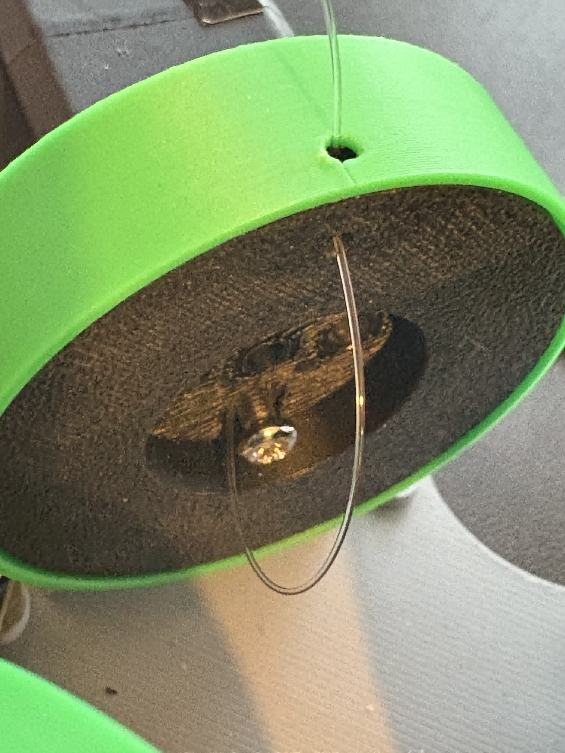
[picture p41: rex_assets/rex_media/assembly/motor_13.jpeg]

</div>

Test the wire security by pulling firmly. The wire should remain securely fastened. This method, while hacky, provides reliable wire retention.

<div align="center">
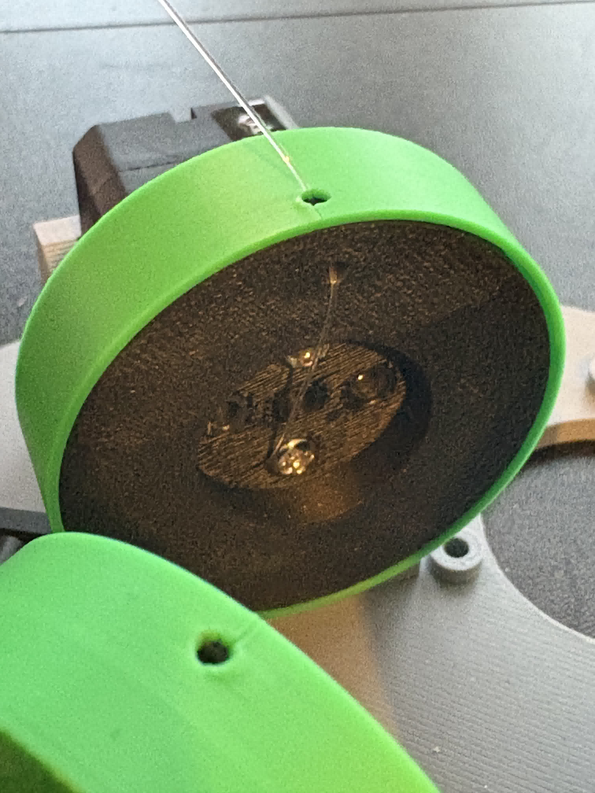
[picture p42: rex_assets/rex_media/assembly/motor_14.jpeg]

</div>

Repeat this procedure for the remaining two fishing wires and motors.

<div align="center">
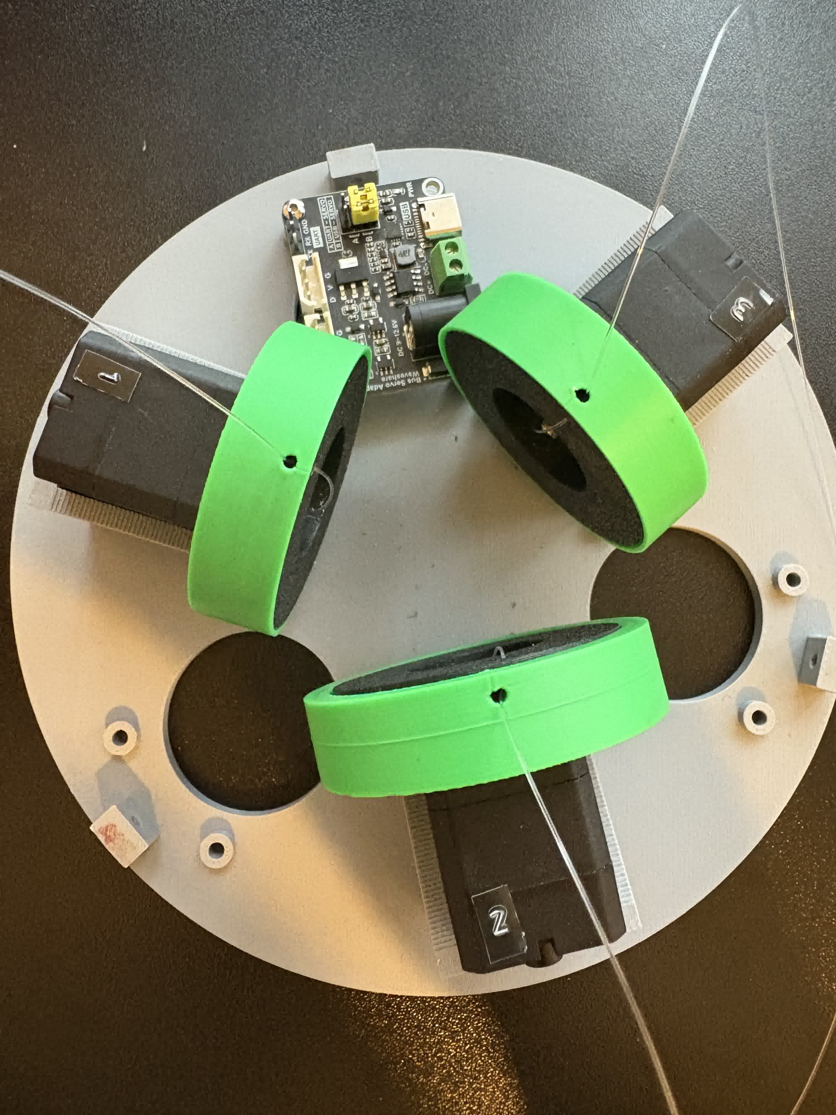
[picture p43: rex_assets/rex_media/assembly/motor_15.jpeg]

</div>

Connect the motors in sequence: Motor 2 to Motor 3, Motor 3 to Motor 1, and Motor 1 to the driver board.

<div align="center">
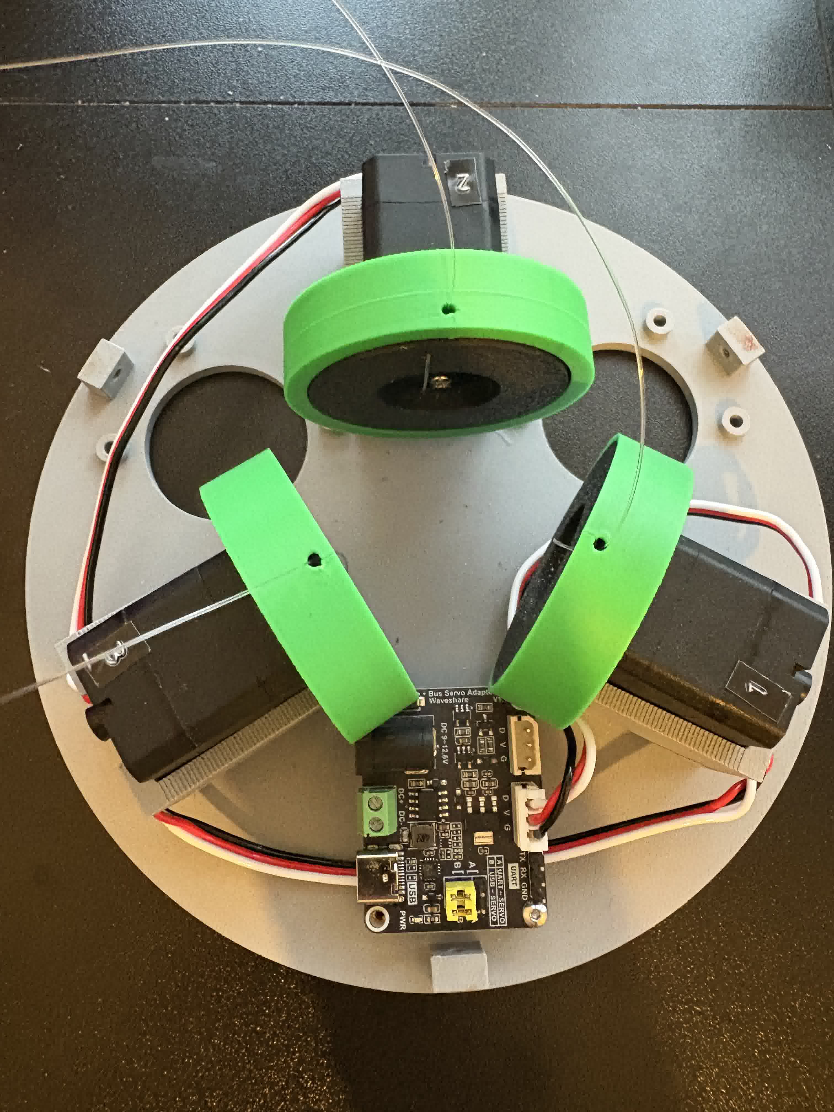
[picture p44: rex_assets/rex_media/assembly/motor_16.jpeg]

</div>

### Final Assembly

Begin final assembly by routing the three cables (camera, driver board data, and driver board power) through the dome opening. Connect the camera cable to the camera.

<div align="center">
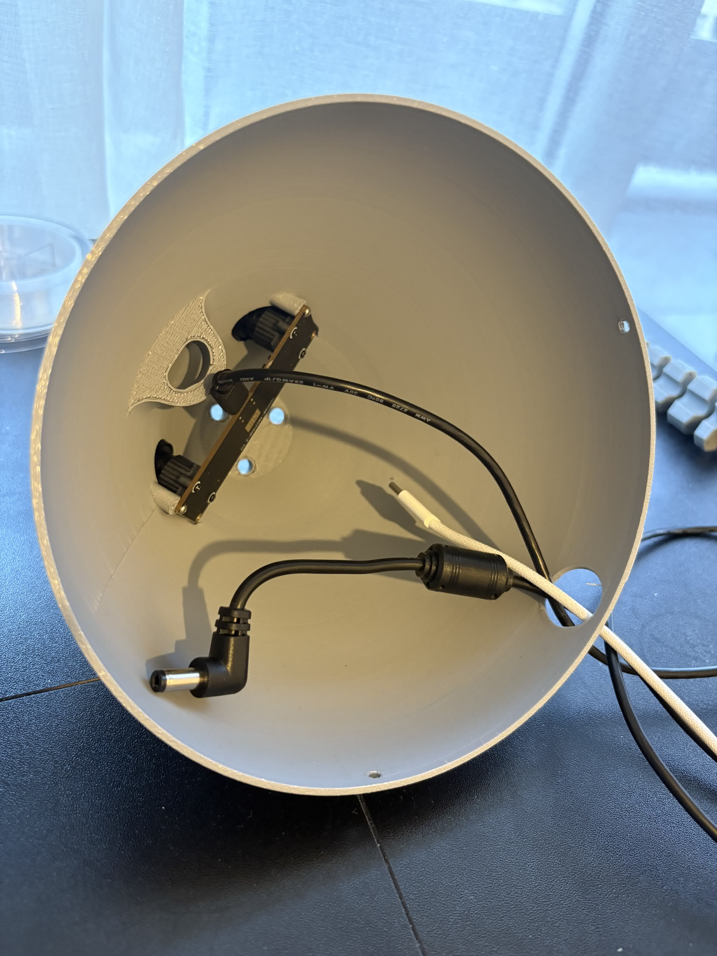
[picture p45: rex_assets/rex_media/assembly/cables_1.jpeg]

</div>

Connect the data and power cables to the driver board.

<div align="center">
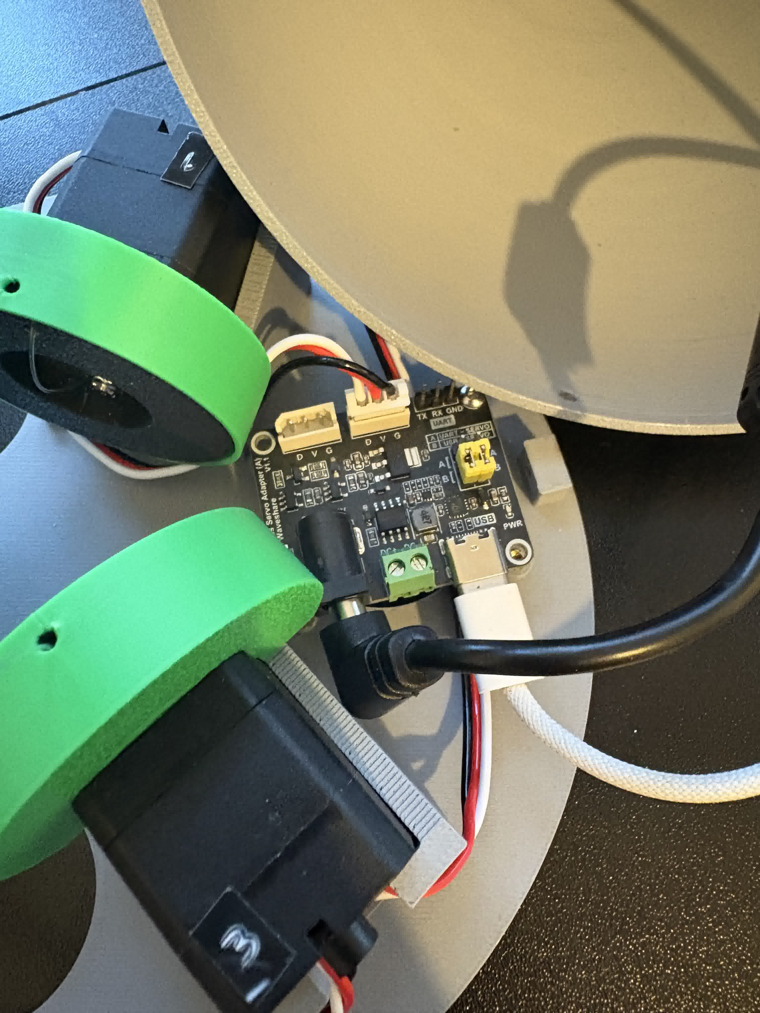
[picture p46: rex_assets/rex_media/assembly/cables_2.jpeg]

</div>

Thread each fishing wire through the corresponding holes in the dome top. Pay careful attention to the following:
- Wire 2 (front tendon actuator) must pass through the small tunnel to prevent camera interference when tensioned
- Each wire ID must correspond to the correct dome hole
- Route fishing wires beneath the camera cable to prevent interference during operation

Position the dome and pull the cables and fishing wires taut. Use the through-holes in the plate to verify proper cable routing from below.

<div align="center">
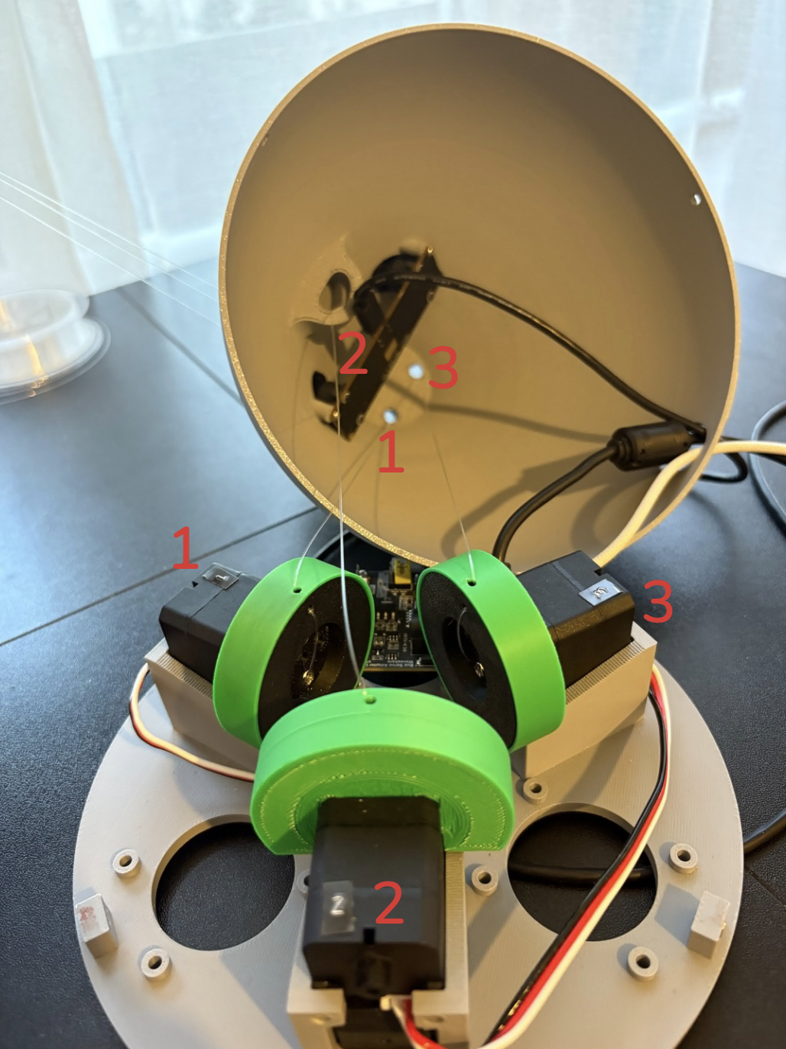
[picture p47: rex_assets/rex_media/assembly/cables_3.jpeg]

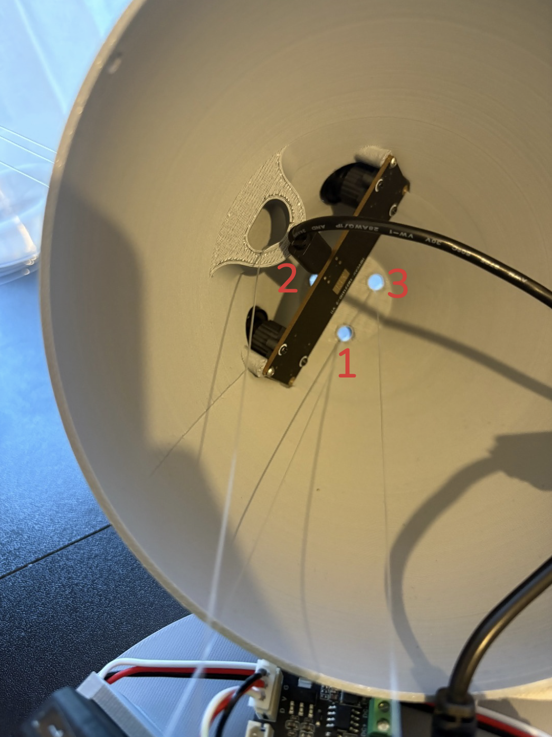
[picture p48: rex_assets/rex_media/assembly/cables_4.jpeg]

</div>
<div align="center">
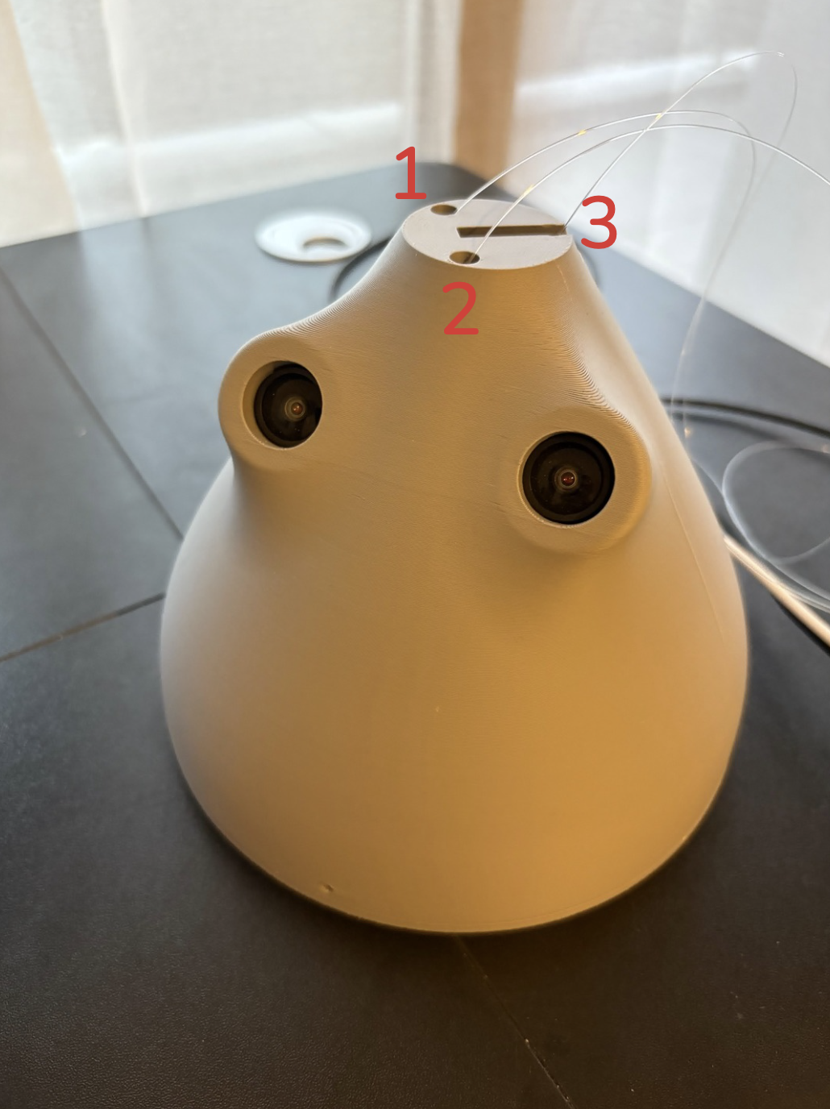
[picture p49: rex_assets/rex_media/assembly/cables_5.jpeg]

</div>

Secure the dome with 3x M2.5 × 6mm screws.

<div align="center">
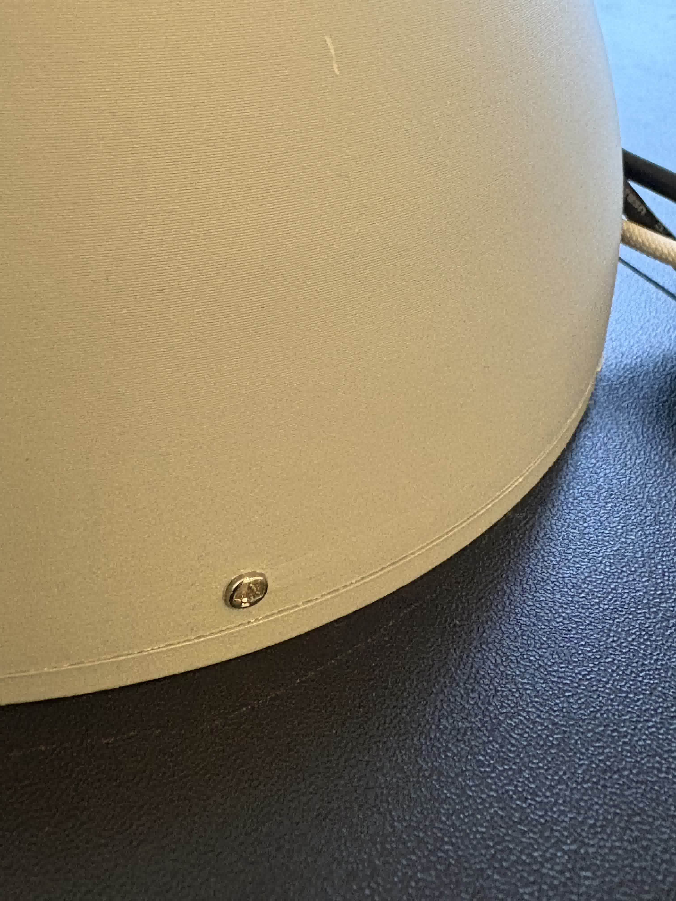
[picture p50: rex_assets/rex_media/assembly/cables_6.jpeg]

</div>

Thread the fishing wires through the tentacle. Ensure proper hole alignment as shown below, then feed each wire completely through all holes. Work with one wire at a time for best results.

<div align="center">
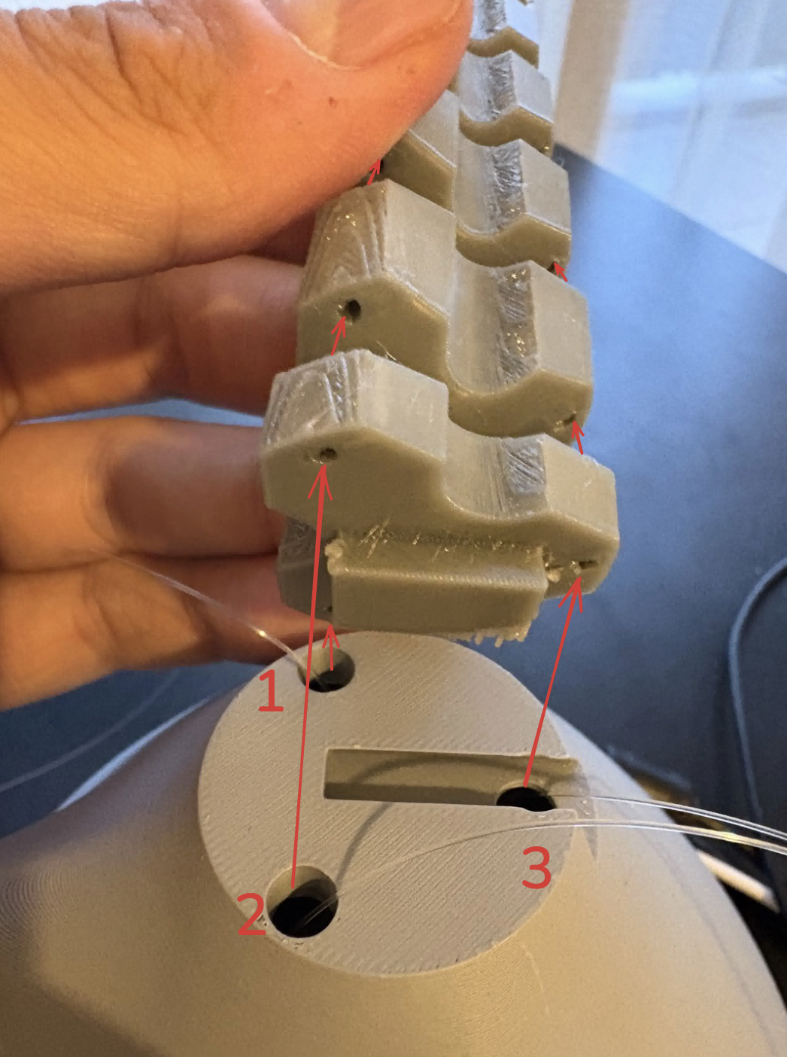
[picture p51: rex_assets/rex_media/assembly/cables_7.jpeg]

</div>

Once complete, pull all wires taut as shown.

<div align="center">
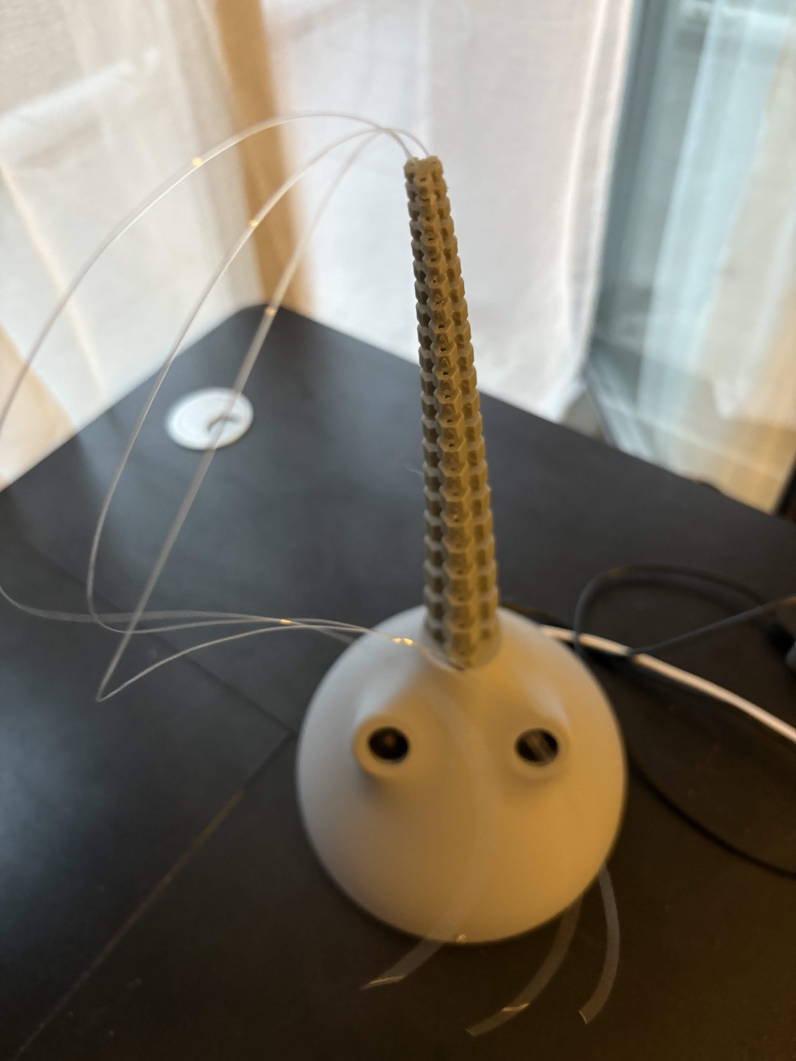
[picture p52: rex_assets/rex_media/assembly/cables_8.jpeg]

</div>

Before securing the wires with knots, remove excess slack using the calibration script. The 80cm wire length exceeds the resting length requirement for three important reasons:

1. **Control Range**: The software requires approximately one full rotation (≈11cm) of wire movement in each direction for proper tentacle articulation and slack management
2. **Maintenance Access**: Extra length allows dome inspection and internal work without untying knots and repeating the wire installation process
3. **Recalibration**: Provides adjustment capability for optimal rest position calibration

Run the calibration script for initial pre-rolling (we'll finetune the rest position later):

```bash
python -m rex_tendon calibrate --config rex_tendon/configs/default_hardware.yaml
```

Use the arrow keys (left, top, right) to wind the motors and remove slack. Press spacebar to reverse winding direction if needed. Note that the robot controllers expects you to roll them using the direction that comes at the start of the script. Do not change the rolling direction without doing the necessary software/config changes (I don't think it's configurable everywhere in the code yet).

Leave approximately 10cm of wire length for knot tying.

<div align="center">
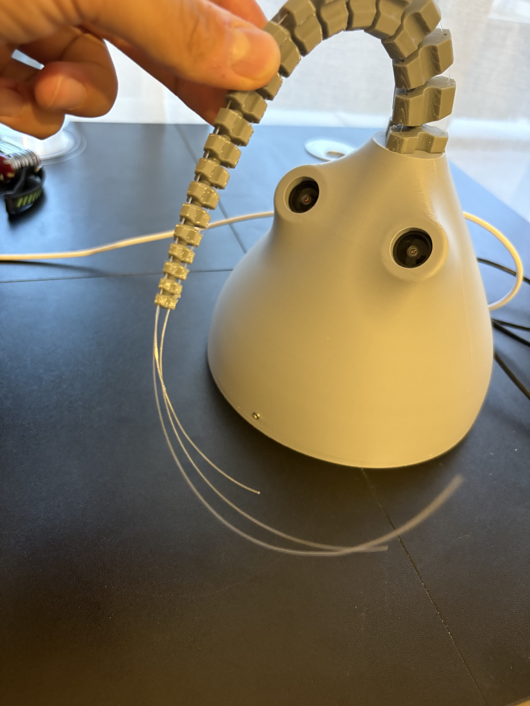
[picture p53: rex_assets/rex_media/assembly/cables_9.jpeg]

</div>

For optimal wire securing, avoid direct knotting. Instead, create a loop with each wire and re-thread it through the final hole. This method provides better tension distribution and reduces the risk of loosening during operation. Pull each wire taut to eliminate slack. The tentacle should remain straight after this step.

<div align="center">
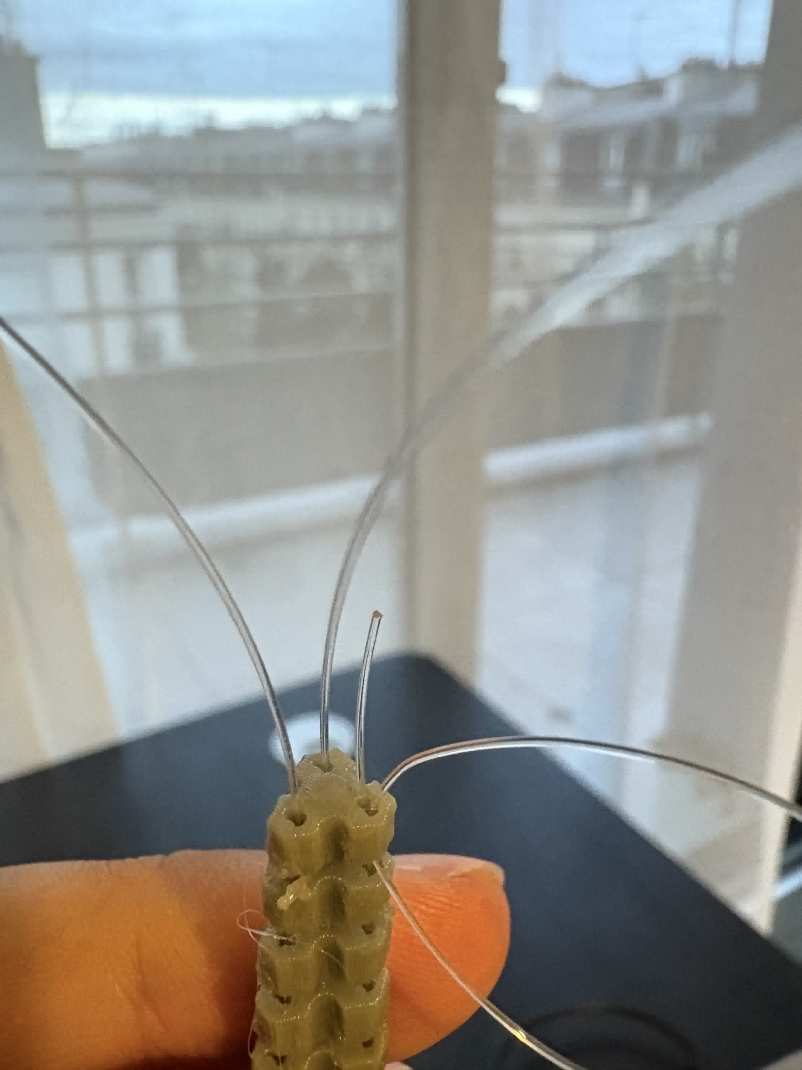
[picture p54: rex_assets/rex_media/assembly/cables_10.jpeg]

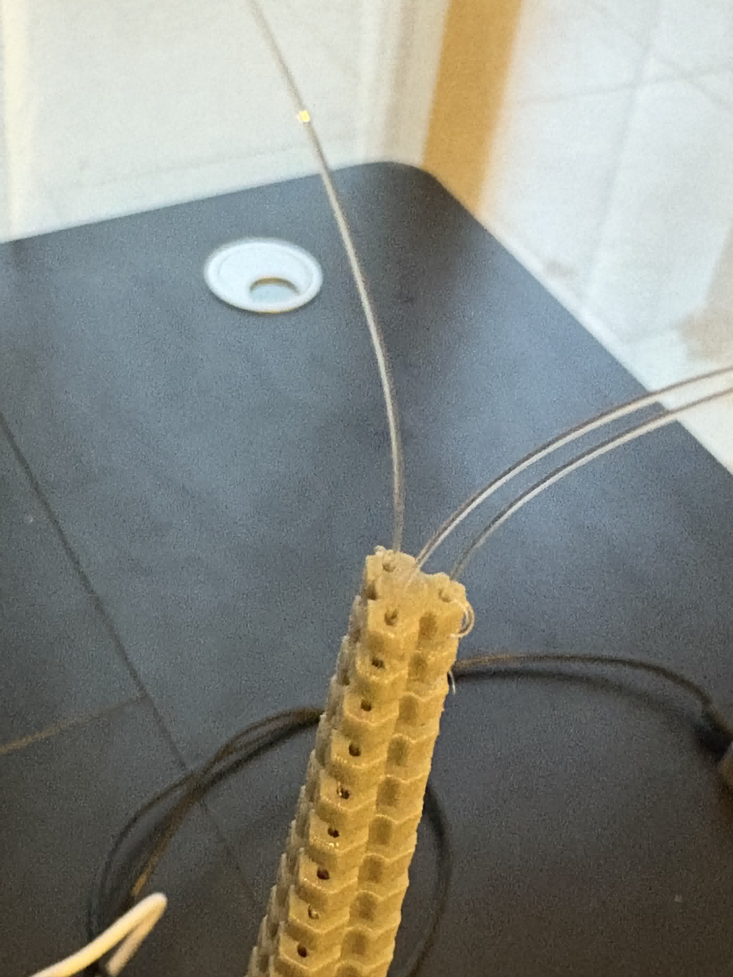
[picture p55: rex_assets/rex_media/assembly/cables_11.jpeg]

</div>

Tie a secure knot and pull firmly to test. Trim excess wire length, leaving at least 3cm for potential unknotting if needed.

<div align="center">

</div>

Tuck the remaining wire length into the spike tentacle tip and insert the spike into the first segment of the tentacle.

### Final Calibration

Perform the final tentacle calibration to ensure all wires are at their proper rest length. Run the calibration script and adjust using the arrow keys until the tentacle stands upright:

```bash
python -m rex_tendon calibrate --config rex_tendon/configs/default_hardware.yaml
```

This script saves calibration data to `rex_assets/rex_hardware/calibration/tentacle_calibration.json`, which will be automatically loaded by the control software later.

**Important calibration notes:**
- Avoid excessive wire unwinding during calibration (unless the dome is also being pulled away to maintain tension)
- Prevent over-tightening of cables (see comparison images below)

<table align="center">
<tr>
<td align="center">

<br>
<em>Proper cable tension</em>
</td>
<td align="center">

<br>
<em>Over-tensioned - avoid this</em>
</td>
</tr>
</table>

A properly calibrated tentacle tip should exhibit "chicken head" behavior: remaining relatively stable as you twist and bend the tentacle body.

<div align="center">

</div>

Done!

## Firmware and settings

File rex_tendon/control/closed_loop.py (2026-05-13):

"""Closed-loop control system combining vision and motor control."""

import logging
import time
from pathlib import Path
from dataclasses import dataclass, field
from typing import Any, Deque, Dict, Optional, Tuple
from collections import deque
from concurrent.futures import ThreadPoolExecutor

import cv2
import numpy as np
import typer
from rich.console import Console
from stable_baselines3 import PPO

from ..perception.detection import YOLODetector
from ..perception.hand_tracking import get_mediapipe_hand_data, close_mediapipe_hands
from ..perception.stereo import (
    triangulate_points,
    load_stereo_calibration,
    split_stereo_frame,
)

from ..hardware.motors import MotorController
from ..common.constants import MOTOR_NAMES

from .geometry import cursor_to_motor_positions

from rex_tendon.configs import (
    get_control_config,
    get_perception_config,
    get_hardware_config,
)

logger = logging.getLogger(__name__)
console = Console()
app = typer.Typer(help="Closed-loop RL control")


@dataclass
class CableMapper:
    """Utility for converting motor ticks to cable lengths for observations."""

    ticks_per_rotation: int
    length_per_rotation: float
    baseline_length: float
    tick_sign: int = 1

    length_per_tick: float = field(init=False)

    def __post_init__(self):
        self.length_per_tick = self.length_per_rotation / float(self.ticks_per_rotation)

    def ticks_to_length(self, ticks: int, calibrated_zero_ticks: int) -> float:
        """Converts *absolute* motor ticks to cable length in metres."""
        rel_ticks = ticks - calibrated_zero_ticks
        return self.baseline_length + rel_ticks * self.length_per_tick * self.tick_sign

    def get_cable_lengths_from_positions(
        self,
        positions_ticks: Dict[str, int],
        calib_ticks_map: Dict[str, int],
    ) -> np.ndarray:
        """Convert motor positions to cable lengths array for RL observations."""
        lengths = np.zeros(3, dtype=np.float32)
        for motor_name in MOTOR_NAMES:
            if motor_name in positions_ticks:
                sim_idx = int(motor_name) - 1
                lengths[sim_idx] = self.ticks_to_length(
                    positions_ticks[motor_name], calib_ticks_map[motor_name]
                )
        return lengths


class ObservationBuffer:
    """Maintains a fixed-length buffer of stacked observation frames."""

    def __init__(self, num_frames: int, frame_shape: int):
        self.buffer: Deque[np.ndarray] = deque(maxlen=num_frames)
        self.num_frames = num_frames
        self.frame_shape = frame_shape

    def _build_single_frame_obs(
        self,
        tip_pos_m: np.ndarray,
        target_pos_m: np.ndarray,
        actuator_lengths_m: Optional[np.ndarray] = None,
        clip_obs: bool = False,
        clip_bounds: Optional[Dict[str, Any]] = None,
    ) -> np.ndarray:
        """Formats a single observation frame, optionally clipping values."""

        # Transform tip and target positions to match the policy's input format
        tip_pos_transformed = np.array(
            [tip_pos_m[2], tip_pos_m[0], tip_pos_m[1]], dtype=np.float32
        )
        target_pos_transformed = np.array(
            [target_pos_m[2], target_pos_m[0], target_pos_m[1]], dtype=np.float32
        )

        obs_parts = [tip_pos_transformed, target_pos_transformed]

        obs_parts.append(actuator_lengths_m.astype(np.float32).copy())

        raw_obs_frame = np.concatenate(obs_parts).astype(np.float32)
        raw_obs_frame = np.round(raw_obs_frame, 2)

        if clip_obs and clip_bounds is not None:
            raw_obs_frame[0:3] = np.clip(
                raw_obs_frame[0:3],
                clip_bounds.get("tip_min", -np.inf),
                clip_bounds.get("tip_max", np.inf),
            )
            raw_obs_frame[3:6] = np.clip(
                raw_obs_frame[3:6],
                clip_bounds.get("target_min", -np.inf),
                clip_bounds.get("target_max", np.inf),
            )
            if actuator_lengths_m is not None and len(raw_obs_frame) >= 9:
                raw_obs_frame[6:9] = np.clip(
                    raw_obs_frame[6:9],
                    clip_bounds.get("actuator_length_min", -np.inf),
                    clip_bounds.get("actuator_length_max", np.inf),
                )

        return raw_obs_frame

    def append(
        self,
        tip_pos_m: np.ndarray,
        target_pos_m: np.ndarray,
        actuator_lengths_m: Optional[np.ndarray] = None,
        clip_obs: bool = False,
        clip_bounds: Optional[Dict[str, Any]] = None,
    ) -> np.ndarray:
        """Build observation frame and add to buffer, returning stacked observation."""
        frame = self._build_single_frame_obs(
            tip_pos_m=tip_pos_m,
            target_pos_m=target_pos_m,
            actuator_lengths_m=actuator_lengths_m,
            clip_obs=clip_obs,
            clip_bounds=clip_bounds,
        )

        self.buffer.append(frame.astype(np.float32).copy())

        # For the first few frames, we need to pad the buffer
        while len(self.buffer) < self.num_frames:
            self.buffer.append(frame.astype(np.float32).copy())

        return np.concatenate(list(self.buffer), axis=0)


class PerceptionSystem:
    """Handles camera input, object detection, and stereo vision processing."""

    def __init__(
        self,
        perception_config,
        camera_index: Optional[int] = None,
        external_camera: Optional[cv2.VideoCapture] = None,
    ):
        """Initialize perception system.

        Args:
            perception_config: Perception configuration object
            camera_index: Camera index to use (overrides config if provided)
            external_camera: External camera object to use instead of creating new one
        """
        self.config = perception_config
        self.cap = external_camera
        self.owns_camera = external_camera is None
        self.executor = None

        # Initialize camera if not provided externally
        if self.cap is None:
            camera_idx = (
                camera_index if camera_index is not None else self.config.camera_index
            )
            self.cap = cv2.VideoCapture(camera_idx)
            if not self.cap.isOpened():
                raise RuntimeError(f"Cannot open camera {camera_idx}")
            self.cap.set(cv2.CAP_PROP_FRAME_WIDTH, self.config.stereo_resolution[0])
            self.cap.set(cv2.CAP_PROP_FRAME_HEIGHT, self.config.stereo_resolution[1])

        # Get frame dimensions
        frame_width = int(self.cap.get(cv2.CAP_PROP_FRAME_WIDTH))
        self.half_width = frame_width // 2

        # Initialize perception modules
        self.stereo_calib = load_stereo_calibration(
            calib_dir=self.config.camera_calibration_path
        )
        self.detector = YOLODetector(
            model_path=str(self.config.yolo_model_path),
            device=self.config.yolo_device,
            confidence_threshold=self.config.confidence_threshold,
        )

    def start_parallel_processing(self):
        """Start thread pool for parallel processing."""
        if self.executor is None:
            self.executor = ThreadPoolExecutor(max_workers=4)

    def get_detections(self) -> Tuple[Optional[np.ndarray], Optional[np.ndarray]]:
        """Get tip and finger positions from current camera frame.

        Returns:
            Tuple of (tip_position, finger_position) in world coordinates
        """
        if not self.cap:
            return None, None

        ok, frame = self.cap.read()
        if not ok:
            return None, None

        left_frame, right_frame = split_stereo_frame(frame)

        if self.executor:
            # Parallel processing
            future_left_tip = self.executor.submit(self.detector.detect, left_frame)
            future_right_tip = self.executor.submit(self.detector.detect, right_frame)
            future_left_finger = self.executor.submit(
                get_mediapipe_hand_data, left_frame
            )
            future_right_finger = self.executor.submit(
                get_mediapipe_hand_data, right_frame
            )

            xy_l_tip, _, _ = future_left_tip.result()
            xy_r_tip, _, _ = future_right_tip.result()
            xy_l_finger, _ = future_left_finger.result()
            xy_r_finger, _ = future_right_finger.result()
        else:
            # Sequential processing
            xy_l_tip, _, _ = self.detector.detect(left_frame)
            xy_r_tip, _, _ = self.detector.detect(right_frame)
            xy_l_finger, _ = get_mediapipe_hand_data(left_frame)
            xy_r_finger, _ = get_mediapipe_hand_data(right_frame)

        # Triangulate 3D positions
        tip_pos = triangulate_points(
            xy_l_tip,
            xy_r_tip,
            self.stereo_calib,
            units_to_m=self.config.units_to_meters,
            rotation_angle_deg=self.config.rotation_angle_deg,
            y_translation_m=self.config.y_translation_m,
            coordinate_limits=self.config.coordinate_limits,
        )

        finger_pos = triangulate_points(
            xy_l_finger,
            xy_r_finger,
            self.stereo_calib,
            units_to_m=self.config.units_to_meters,
            rotation_angle_deg=self.config.rotation_angle_deg,
            y_translation_m=self.config.y_translation_m,
            coordinate_limits=self.config.coordinate_limits,
        )

        return tip_pos, finger_pos

    def cleanup(self):
        """Clean up resources."""
        if self.executor:
            self.executor.shutdown()
            self.executor = None
        if self.cap and self.owns_camera:
            self.cap.release()
            self.cap = None
        close_mediapipe_hands()


class RLInferenceEngine:
    """Handles RL model loading, observation processing, and action inference."""

    def __init__(self, control_config):
        """Initialize RL inference engine."""
        self.config = control_config
        self.policy = None
        self.obs_buffer = None

        # Load RL model
        model_path = self.config.model_path
        if not Path(model_path).exists():
            raise FileNotFoundError(f"SB3 model not found at {model_path}")
        self.policy = PPO.load(model_path)

        # Set up observation buffer
        obs_dim_single = 6
        if self.config.include_actuator_lengths_in_obs:
            obs_dim_single += 3

        self.obs_buffer = ObservationBuffer(self.config.num_frames, obs_dim_single)

        # Prepare observation clipping
        self.clip_observations = self.config.clip_observations
        self.obs_clip_bounds = self.config.obs_clip_bounds.copy()
        if self.clip_observations:
            for key in ["tip_min", "tip_max", "target_min", "target_max"]:
                if key in self.obs_clip_bounds:
                    self.obs_clip_bounds[key] = np.array(
                        self.obs_clip_bounds[key], dtype=np.float32
                    )

        # Action smoothing
        self.previous_action: Optional[np.ndarray] = None
        self.action_smoothing_alpha = control_config.action_smoothing_alpha

        # Action calibration offset
        self.action_2d_offset = np.array(
            control_config.action_2d_offset, dtype=np.float32
        )

    def predict_action(
        self,
        tip_pos: np.ndarray,
        target_pos: np.ndarray,
        actuator_lengths: Optional[np.ndarray] = None,
    ) -> np.ndarray:
        """Predict action from current state.

        Args:
            tip_pos: Current tip position
            target_pos: Target position
            actuator_lengths: Current actuator lengths (optional)

        Returns:
            Predicted 2D cursor action (smoothed)
        """
        # Build observation
        obs_args = {
            "tip_pos_m": tip_pos.astype(np.float32),
            "target_pos_m": target_pos.astype(np.float32),
            "clip_obs": self.clip_observations,
            "clip_bounds": self.obs_clip_bounds,
        }
        if self.config.include_actuator_lengths_in_obs and actuator_lengths is not None:
            obs_args["actuator_lengths_m"] = actuator_lengths

        obs = self.obs_buffer.append(**obs_args)

        # Get raw policy action
        raw_action, _ = self.policy.predict(
            obs, deterministic=self.config.deterministic
        )
        raw_action = np.asarray(raw_action, dtype=np.float32)

        # Apply action smoothing using exponential moving average
        if self.previous_action is None:
            # First action - no smoothing needed
            smoothed_action = raw_action.copy()
        else:
            # Smooth with previous action: new_action = alpha * raw + (1-alpha) * previous
            smoothed_action = (
                self.action_smoothing_alpha * raw_action
                + (1.0 - self.action_smoothing_alpha) * self.previous_action
            )

        # Update previous action for next iteration
        self.previous_action = smoothed_action.copy()

        # Apply calibration offset
        final_action = smoothed_action + self.action_2d_offset

        return final_action


class MotorSystem:
    """Handles motor control, cable mapping, and safety constraints."""

    def __init__(
        self,
        hardware_config,
        control_config,
        external_motor_controller: Optional[MotorController] = None,
    ):
        """Initialize motor system.

        Args:
            hardware_config: Hardware configuration
            control_config: Control configuration
            external_motor_controller: External motor controller to use
        """
        self.hardware_config = hardware_config
        self.control_config = control_config
        self.motor_controller = external_motor_controller
        self.owns_motor_controller = external_motor_controller is None

        if self.motor_controller is None:
            self.motor_controller = MotorController(hardware_config)

        self.cable_mapper = CableMapper(
            ticks_per_rotation=hardware_config.ticks_per_rotation,
            length_per_rotation=hardware_config.length_per_rotation,
            baseline_length=hardware_config.baseline_length,
            tick_sign=hardware_config.tick_sign,
        )

        self.calib_ticks_map = {}
        self.current_positions_ticks = {}
        self.current_cable_lengths_sim_m = None

    def connect(self):
        """Connect to motors and initialize."""
        if self.owns_motor_controller:
            self.motor_controller.connect()
        self.calib_ticks_map = self.motor_controller.get_calibration_data()
        self.current_positions_ticks = self.motor_controller.get_positions()

        # Initialize current cable lengths
        self.current_cable_lengths_sim_m = (
            self.cable_mapper.get_cable_lengths_from_positions(
                self.current_positions_ticks, self.calib_ticks_map
            )
        )

    def safe_set_motor_positions_ticks(self, target_map_ticks: Dict[str, int]):
        """Set motor positions with safety limits."""
        safety_min_off = self.control_config.safety_offset_min
        safety_max_off = self.control_config.safety_offset_max

        guarded_ticks: Dict[str, int] = {}
        for m_name, ticks in target_map_ticks.items():
            zero = self.calib_ticks_map[m_name]
            min_tick = zero + safety_min_off
            max_tick = zero + safety_max_off
            clamped_ticks = np.clip(ticks, min_tick, max_tick)
            if ticks != clamped_ticks:
                console.print(
                    f"Guardrail clamp {m_name}: {ticks} -> {clamped_ticks} "
                    f"(limits [{min_tick}, {max_tick}])"
                )
            guarded_ticks[m_name] = clamped_ticks

        self.motor_controller.set_positions(guarded_ticks)

        # Read back actual motor positions
        actual_positions = self.motor_controller.get_positions()
        self.current_positions_ticks.update(actual_positions)

        # Update cable lengths based on actual positions
        self.current_cable_lengths_sim_m = (
            self.cable_mapper.get_cable_lengths_from_positions(
                self.current_positions_ticks, self.calib_ticks_map
            )
        )

    def execute_action(self, action_2d: np.ndarray) -> np.ndarray:
        """Execute 2D cursor action using direct motor position conversion.

        Args:
            action_2d: 2D cursor action

        Returns:
            New cable lengths after action execution
        """
        # Convert 2D action directly to motor positions
        target_positions, _ = cursor_to_motor_positions(
            action_2d,
            self.calib_ticks_map,
            noise_scale=0.0,
        )

        # Send motor commands
        self.safe_set_motor_positions_ticks(target_positions)

        return self.current_cable_lengths_sim_m

    def run_calibration(self) -> Dict[str, int]:
        """Run direct 2D position calibration."""
        return self._calibrate_to_2d_position()

    def _calibrate_to_2d_position(self) -> Dict[str, int]:
        """Move smoothly to configured 2D calibration position with interpolation and noise."""
        calibration_2d_pos = np.array(
            self.control_config.calibration_2d_position, dtype=np.float32
        )

        logger.info(f"Moving to calibration position: {calibration_2d_pos}")

        # Get current 2D position by inferring from current motor positions
        # We'll start from neutral [0, 0] as a reasonable approximation
        start_2d_pos = np.array([0.0, 0.0], dtype=np.float32)

        # Interpolation parameters
        num_steps = 20
        base_noise_scale = 0.04
        step_duration = 0.01

        logger.info(
            f"Interpolating from {start_2d_pos} to {calibration_2d_pos} in {num_steps} steps"
        )

        # Generate interpolated positions with noise for realism
        for i in range(num_steps + 1):
            # Linear interpolation factor
            alpha = i / num_steps

            # Interpolated position
            interp_pos = start_2d_pos + alpha * (calibration_2d_pos - start_2d_pos)

            # Add decreasing noise (more noise at start, less at end for smooth settling)
            noise_scale = base_noise_scale * (1.0 - alpha)

            # Convert to motor positions with noise
            target_positions, _ = cursor_to_motor_positions(
                interp_pos,
                self.calib_ticks_map,
                noise_scale=noise_scale,
            )

            # Apply the interpolated position
            self.safe_set_motor_positions_ticks(target_positions)

            # Small delay between steps for smooth movement
            if i < num_steps:  # Don't sleep after final step
                time.sleep(step_duration)

        logger.info(
            f"Calibration complete. Motors moved to ticks: {self.current_positions_ticks}"
        )
        return self.current_positions_ticks

    def cleanup(self, reset_to_calibrated: bool = True):
        """Clean up motor system.

        Args:
            reset_to_calibrated: Whether to reset motors to calibrated positions
                before disconnecting
        """
        if self.motor_controller and self.owns_motor_controller:
            try:
                # Only reset if still connected and requested
                if self.motor_controller.is_connected and reset_to_calibrated:
                    self.motor_controller.reset_to_calibrated_positions()
            finally:
                if self.motor_controller.is_connected:
                    self.motor_controller.disconnect()
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

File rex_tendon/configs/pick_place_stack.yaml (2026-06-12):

# Stage B stacking curriculum: 2-section (4-DOF) arm rebuilds a source stack at a
# target location, ramping stack height 2 -> 3 as it masters each level
# (reuses the multi-object curriculum: stack_count follows the shared level).
#
# WARM-START THIS from the pick_place_2section foundation policy:
#   pick-place train-multi --config .../pick_place_stack.yaml \
#       --init-model rex_results/pick_place_2section/<run>/models/best_model/best_model.zip
# Training stacking from scratch diverges (policy std -> 8e4): the easy proximity
# grasp needs no precision, so ent_coef pushes variance up unchecked. A competent
# 4-DOF base policy + lower ent_coef keeps it stable.
#
# REACH LIMIT: cubes are 2 cm tall; the arm reaches ~0.068 m at the source xy, so
# a source-stack TOP above 3 cubes (z>=0.072) is UNGRASPABLE. Curriculum caps at 3.
pick_place:
  env:
    xml_file: "rex_assets/rex_simulation/pick_and_place_scene_2section.xml"
    # 4-DOF arm tendons are 0.06-0.17; start near rest (slightly slack).
    initial_actuator_position: [0.13, 0.17]
    simulation_length_seconds: 20.0   # multiple cubes per episode

    # Stacking height curriculum 2 -> 3 (bumps when place_success > 90%).
    # Capped at 3: a 4-high source stack's top cube is beyond the arm's reach.
    object_curriculum_enabled: true
    min_spawned_objects: 2
    max_spawned_objects: 3

    # Grasp trigger: hybrid (contact OR proximity). Contact-only was probed
    # (2026-06-11): random approaches achieve force-bearing contact in 0.7% of
    # episodes and latch in 0.3% — undiscoverable for RL; runs 2 & 3 (12M each)
    # both collapsed to 0% grasping under grasp_requires_contact: true. Since
    # the carry is assisted regardless, the trigger's realism was cosmetic;
    # placement below is where physics is the judge. Grasp realism = documented
    # limitation (future work: wrap-grasp contact physics).
    grasp_requires_contact: false
    grasp_distance_threshold: 0.035
    grasp_consecutive_steps: 2
    # Carry depth: the tip's contact sphere is 8 mm; at 0.015 the carried
    # cube's top sat 3 mm INSIDE it, so the per-step assist snap re-created
    # penetration and the contact impulses shook the arm — run-4 logs show
    # carried cubes flung to 0.65-0.77 m from the slot. 0.025 keeps the cube
    # 7 mm clear of the sphere.
    grasp_carry_offset: 0.025
    # PLACEMENT ACCURACY (kept): the cube is released above the slot and must
    # physically land within tolerance + survive the topple check. Oracle probe:
    # 12/300 random-action carries complete a real placement -> discoverable.
    place_mode: release
    place_settle_steps: 6             # ~0.5 s of physics before judging
    # Run-7 tolerance matching: run 6 proved the policy carries the cube to
    # 5-6 cm of any commanded target (verified det+stochastic rollouts), but
    # the 3 cm trigger sat ~2 cm inside that precision — snapshot policies
    # hovered at the line and rarely fired. 4.5 cm puts the trigger inside
    # the demonstrated envelope (still within the scene's 6 cm zone disc);
    # the place bonus then tightens precision from frequent successes.
    place_distance_threshold: 0.045   # release trigger + settled-cube tolerance
    # Holding (0.15/step) must beat hovering near the cube: cap the proximity
    # shaping at 0.1/step (default 0.25 out-paid holding at ~1 cm — run-3 flaw).
    grasp_proximity_bonus_scale: 0.1

    # Reach/grasp phase transfers fast; enter placing early.
    curriculum_enabled: true
    reach_only_steps: 0
    reach_grasp_steps: 100000
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

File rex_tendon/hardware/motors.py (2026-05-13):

"""Motor controller abstraction for Feetech servos."""

import logging
import time
from typing import Dict, Optional, Tuple

from ..configs.hardware import HardwareConfig
from ..common.constants import MOTOR_NAMES
from .calibration import load_calibration, validate_calibration

logger = logging.getLogger(__name__)


class MotorController:
    """Unified motor controller for Feetech servos."""

    def __init__(self, config: Optional[HardwareConfig] = None):
        """Initialize motor controller.

        Args:
            config: Hardware configuration, will create default if None
        """
        self.config = config or HardwareConfig()
        self._motor_bus = None
        self._is_connected = False
        self._calibration_data: Dict[str, int] = {}

    def connect(self) -> None:
        """Connect to motor bus and initialize motors.

        Raises:
            RuntimeError: If connection fails or motors not found
        """
        try:
            # Import Feetech dependencies
            bus_config_cls, bus_cls, _, _ = self._get_motor_bus_classes()

            # Create motor bus configuration
            bus_config = bus_config_cls(
                port=self.config.port,
                motors=self.config.motor_config,
            )

            # Create and connect motor bus
            self._motor_bus = bus_cls(bus_config)
            self._motor_bus.connect()
            logger.info("Connected to motor bus on port %s", self.config.port)

            # Set baudrate
            self._motor_bus.set_bus_baudrate(self.config.baudrate)

            # Verify all motors are present
            self._verify_motors()

            # Initialize motors
            self._initialize_motors()

            # Load calibration
            self._load_calibration()

            self._is_connected = True

        except Exception as e:
            logger.error("Failed to connect to motors: %s", e)
            raise RuntimeError(f"Failed to connect to motors: {e}")

    def disconnect(self) -> None:
        """Disconnect from motor bus."""
        if self._motor_bus and self._is_connected:
            try:
                self._motor_bus.disconnect()
                logger.info("Disconnected from motor bus")
            except Exception as e:
                logger.warning("Error during disconnect: %s", e)
            finally:
                self._is_connected = False
                self._motor_bus = None

    def set_position(self, motor_name: str, position: int) -> None:
        """Set target position for a single motor.

        Args:
            motor_name: Name of the motor
            position: Target position in ticks

        Raises:
            RuntimeError: If motor communication fails
        """
        if not self._is_connected:
            raise RuntimeError("Motor controller not connected")

        if motor_name not in self.config.motor_config:
            raise RuntimeError(f"Unknown motor: {motor_name}")

        try:
            self._motor_bus.write("Goal_Position", position, motor_name)
        except Exception as e:
            logger.error("Failed to set position for motor %s: %s", motor_name, e)
            raise RuntimeError(f"Failed to set position for {motor_name}: {e}")

    def set_positions(self, positions: Dict[str, int]) -> None:
        """Set target positions for multiple motors.

        Args:
            positions: Dictionary mapping motor names to target positions

        Raises:
            RuntimeError: If motor communication fails
        """
        for motor_name, position in positions.items():
            self.set_position(motor_name, position)

    def get_position(self, motor_name: str) -> int:
        """Get current position of a motor.

        Args:
            motor_name: Name of the motor

        Returns:
            Current position in ticks

        Raises:
            RuntimeError: If motor communication fails
        """
        if not self._is_connected:
            raise RuntimeError("Motor controller not connected")

        if motor_name not in self.config.motor_config:
            raise RuntimeError(f"Unknown motor: {motor_name}")

        try:
            return self._motor_bus.read("Present_Position", motor_name)
        except Exception as e:
            logger.error("Failed to read position for motor %s: %s", motor_name, e)
            raise RuntimeError(f"Failed to read position for {motor_name}: {e}")

    def get_positions(self) -> Dict[str, int]:
        """Get current positions of all motors.

        Returns:
            Dictionary mapping motor names to current positions
        """
        positions = {}
        for motor_name in self.config.motor_config.keys():
            positions[motor_name] = self.get_position(motor_name)
        return positions

    def reset_to_calibrated_positions(self) -> None:
        """Reset all motors to their calibrated start positions."""
        if not self._calibration_data:
            logger.warning("No calibration data loaded, resetting to position 0")
            positions = {name: 0 for name in self.config.motor_config.keys()}
        else:
            positions = self._calibration_data.copy()

        logger.info("Resetting motors to calibrated start positions")
        self.set_positions(positions)

        # Wait for motors to settle
        time.sleep(self.config.motor_settle_time)

        # Verify positions
        self._verify_positions(positions)

    def get_calibration_data(self) -> Dict[str, int]:
        """Get the loaded calibration data.

        Returns:
            Dictionary mapping motor names to calibrated positions
        """
        return self._calibration_data.copy()

    @property
    def is_connected(self) -> bool:
        """Check if motor controller is connected."""
        return self._is_connected

    def _get_motor_bus_classes(self) -> Tuple:
        """Get motor bus classes for Feetech motors."""
        try:
            from lerobot.common.robot_devices.motors.configs import (
                FeetechMotorsBusConfig,
            )
            from lerobot.common.robot_devices.motors.feetech import (
                MODEL_BAUDRATE_TABLE,
                SCS_SERIES_BAUDRATE_TABLE,
                FeetechMotorsBus,
            )

            return (
                FeetechMotorsBusConfig,
                FeetechMotorsBus,
                MODEL_BAUDRATE_TABLE,
                SCS_SERIES_BAUDRATE_TABLE,
            )
        except ImportError as e:
            logger.error("Failed to import Feetech motor dependencies: %s", e)
            raise RuntimeError(f"Failed to import Feetech motor dependencies: {e}")

    def _verify_motors(self) -> None:
        """Verify that all configured motors are present."""
        motor_ids = [config[0] for config in self.config.motor_config.values()]
        present_ids = self._motor_bus.find_motor_indices(motor_ids)
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

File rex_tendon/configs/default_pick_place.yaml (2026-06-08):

pick_place:
  env:
    # MuJoCo simulation settings
    xml_file: "rex_assets/rex_simulation/pick_and_place_scene.xml"
    simulation_length_seconds: 12.0
    time_between_steps_seconds: 0.08

    # Actuator/tendon settings
    initial_actuator_position: [0.20, 0.26]

    # Environment objects
    tip_site_name: "tip_center"
    place_zone_site_name: "place_zone"

    # Object configuration
    object_names: ["obj_cube", "obj_cylinder", "obj_bar", "obj_cube_purple", "obj_cube_yellow", "obj_cube_extra_1", "obj_cube_extra_2", "obj_cube_extra_3", "obj_cube_extra_4", "obj_cube_extra_5"]
    object_site_names: ["obj_cube_site", "obj_cylinder_site", "obj_bar_site", "obj_cube_purple_site", "obj_cube_yellow_site", "obj_cube_extra_1_site", "obj_cube_extra_2_site", "obj_cube_extra_3_site", "obj_cube_extra_4_site", "obj_cube_extra_5_site"]
    object_geom_names: ["obj_cube_geom", "obj_cylinder_geom", "obj_bar_geom", "obj_cube_purple_geom", "obj_cube_yellow_geom", "obj_cube_extra_1_geom", "obj_cube_extra_2_geom", "obj_cube_extra_3_geom", "obj_cube_extra_4_geom", "obj_cube_extra_5_geom"]
    grasp_constraint_names: ["grasp_cube", "grasp_cylinder", "grasp_bar", "grasp_purple", "grasp_yellow", "grasp_extra_1", "grasp_extra_2", "grasp_extra_3", "grasp_extra_4", "grasp_extra_5"]

    # Grasping parameters
    grasp_distance_threshold: 0.06
    grasp_consecutive_steps: 3
    place_distance_threshold: 0.06

    # Reward shaping
    reach_reward_scale: 1.0
    grasp_bonus: 5.0
    transport_reward_scale: 2.0
    place_bonus: 10.0
    drop_penalty: 3.0
    action_change_penalty_scale: 0.1
    action_jerk_penalty_scale: 0.02
    object_progress_reward_scale: 4.0
    stable_contact_bonus_scale: 0.1
    assisted_grasp_enabled: false
    assisted_grasp_follow_alpha: 1.0
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

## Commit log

2026-05-13 Initial commit: Rex Tendon Core Robot Files
    [Part1.stl, Part10.stl, Part11.stl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]
2026-06-08 Add base-yaw DOF; fix cameras, object layout, and contact physics in scene
    - Add base_yaw hinge + position actuator at the tentacle root: a 3rd actuated
    task-DOF (true twist). Heavily damped (kp=200, damp=50) on purpose -- yawing
    the compliant 20-joint backbone is a slow mode, so favour a stable,
    overshoot-free reorientation over a snappy/oscillating one.
    - Re-aim robot_cam and workspace_cam via look-at orientations; they were buried
    inside the tentacle / facing the bare table.
    - Re-place all 10 objects to rest stably on the desk (were floating vertical
    stacks that toppled on load); make the cylinder a squat, low-COM puck.
2026-06-08 RL env: hybrid grasp, place_success fix, reachable spawn, rolling metrics
    - Compute place_success in step() (it was never assigned, so episodes never
    terminated successfully -- the root cause of the flat -88 training).
    - Hybrid grasp trigger: real tip-object contact OR proximity, with configurable
    force/distance thresholds; require is_grasped for a successful place.
    - Constrain object spawn to the tip's reachable annulus; spawn a configurable
    number of objects and keep the active target among them.
    - Dense potential-based progress reward toward the place zone; add contact/lift
    telemetry to info.
    - Drive only the 3 tendon actuators and keep the observation 3-tendon, so an
    optional 4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
2026-06-08 Hand control: true wrist-position bend + decoupled hand-roll yaw
    - Drive the bend from wrist POSITION (was palm orientation, so the tip did not
    follow the user's hand movement).
    - Map hand roll/twist to the base-yaw DOF (true twist), decoupled from position
    so the two channels do not fight -- much easier to steer.
    - Adapt cleanly to 3- or 4-actuator models (yaw only when present).
2026-06-08 Voice bridge + tooling: NemoClaw command bridge, voice backends, deps
    - NemoClaw voice-command bridge with dry-run/typed fallbacks for offline use.
    - run_voice_assistant: local (offline) and openai realtime backends.
    - Add deps (ultralytics, typer, rich, websockets, sounddevice, SpeechRecognition);
    tighten pyright include/exclude and report levels.
2026-06-08 Fix place-reward farming: drop per-step lift reward, add living cost
    The per-step transport (lift) reward let the policy farm ~+60 by grasping and
    holding the cube high for a whole episode, which beat placing (place_bonus +
    ending). Deterministic eval was 30% place, with failures hovering ~0.11 m from
    the zone.
    - transport_reward_scale -> 0 in the validate config (the magnetic carry does
    not need lift to transport).
    - Stronger potential-based progress-to-zone and a larger place_bonus.
    - New time_penalty config field + per-step env term (living cost), default 0 so
    other configs are unchanged.
    Result on the single-cube task: deterministic place success 30% -> 100%
    (20/20), episodes ~12 s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
    [pick_place_validate.yaml]
2026-06-08 Add multi-object curriculum (Stage A extension): adaptive ramp + per-count metrics
    - Env: object count read from a shared cross-process counter (ramps 2->5);
    per-episode num_objects, collision (tip<->wrong-object / object<->object), and
    an occlusion proxy (target clutter within occlusion_radius) added to info.
    - MultiObjectCurriculumCallback: buckets grasp/place/episode-length by object
    count, logs collision/occlusion rates, promotes the count when place-success
    > 90% at the current level (after a minimum number of episodes), and saves a
    best checkpoint per curriculum stage. TensorBoard tags under curriculum/*.
    - New `pick-place train-multi` command + pick_place_multi.yaml; logs un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
    [pick_place_multi.yaml]
2026-06-08 Add near-contact grasp option (grasp_carry_offset) + train --init-model warm-start
    - grasp_carry_offset: when set, a grasped object is snapped to a fixed distance
    below the tip (fingertip pickup) instead of freezing the looser proximity
    offset, so the carry looks like a real contact grasp rather than a ~4 cm
    floating crutch. Default None preserves prior behaviour.
    - `train` gains --init-model (warm-start), mirroring train-multi.
    - pick_place_tight.yaml: single-cube near-contact baseline (grasp within 2.5 cm
    or contact, fingertip snap) to measure the success/collision cost before
    Stage B inherits the gripper primitive.
    [pick_place_tight.yaml]
2026-06-08 Stage B M1: 2-section S-curve arm generator + model + roadmap
    - generate-xml --num-sections 2 splits each helical tendon at the mid-segment
    into a lower + upper tendon (6 tendons, 6 actuators, 4 task-DOF), with
    per-section ctrlrange scaled by section length (a full-length rest length
    leaves a half-tendon slack). num_sections=1 is unchanged (3 tendons).
    - Verified: sections bend independently (section0 moves mid-body 111mm vs
    section1 17mm) and the arm forms S-curves (bearing reverses up the chain).
    - tentacle_2section.xml: generated 2-section model.
    - STAGE_B_PLAN.md: milestones M1(done)->M7 (control map, 2-section scene, env,
    stacking task, curriculum, tighter-grasp payoff).
    Co-A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
2026-06-08 Stage B M2: convert_4d_cursor_to_target_lengths (2-section control map)
    Two stacked 2D cursors [s1_x,s1_y,s2_x,s2_y] -> 6 tendon lengths, each section
    reusing the single-section 2D->3 map so the halves bend independently (4 DOF).
    Verified: section1/section2 bend independently; combined cursors form S-curves.
2026-06-08 Stage B M3: 2-section pick-place scene + programmatic transform
    make_two_section_scene() splits the 3 helical tendons at body 10 into 6 tendons
    (lower 1-3, upper 4-6) with per-section ctrlrange, rewriting only the tendon and
    actuator blocks and preserving desk/objects/base-yaw/cameras verbatim. Output
    pick_and_place_scene_2section.xml loads with 7 actuators (6 tendons + base_yaw),
    all objects + tip site intact.
2026-06-08 Stage B M4: env adapts to 1- or 2-section arm (auto-detect DOF)
    Detect tendon-actuator count from the model (3 per section): 1 section -> 2D
    action / 3 tendons (Stage A, unchanged, obs=(60,)), 2 sections -> 4D action / 6
    tendons (obs=(80,)), driving convert_4d. calibrated_tendon_lengths is now an
    array; obs base is 10+action_dim. Verified both models load, step, and bend;
    Stage A regression tests still pass.
2026-06-09 Stage B M5: stacking task (top-of-stack pick, rising target, N-cube success)
    Task config gains stacking/stack_count/source_xy/target_xy. In stacking mode the
    env spawns a source stack (cube i at z = surf + (i+.5)*h), the active object is
    pinned to the source top (not nearest), and the place target is the rising slot
    (z = surf + (.5+num_placed)*h at target_xy). Each carried cube within
    place_distance of the slot is snapped on and released (num_placed++); success =
    all N placed without the target stack toppling. Reuses Stage A reward scaffolding
    (reach/grasp/progress) + per-cube place bonus + topple penalty.
    Verified: 2-cube stack picks top-first, advances slots, succeeds on cube 2.
    Co-Autho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
2026-06-09 Stage B M6: stacking curriculum (2->4) reusing the shared level + training config
    In stacking mode the stack height follows the object-curriculum level when
    enabled, so the existing MultiObjectCurriculumCallback ramps 2->3->4 as the
    policy masters each (place_success>90%). pick_place_stack.yaml: 4-DOF scene,
    stacking task (source 0.08, target -0.08), near-contact grasp (the 4-DOF arm
    reaches the table z~0.01), curriculum min=2/max=4. Smoke-tested end to end.
2026-06-10 Repo hygiene: stop ignoring tests, fix pytest/poetry config, add gitattributes
    - .gitignore: tests/, test_*.py, implementation_plan.md, visualize_model.py
    were git-ignored, leaving the RL regression suite and all unit tests
    out of version control. Now tracked. Ignore _train_*.log watcher logs
    and editor .code-workspace files instead.
    - pyproject: drop --cov addopts (pytest-cov not installed; broke every
    bare pytest run) and point the poetry script at the real entrypoint
    rex_tendon.__main__:main (rex_tendon/cli.py does not exist).
    - .gitattributes: normalize text to LF, mark binary assets.
    - Track: RL env regression tests, new control modules (smoothing,
    realtime, voice_commands)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
2026-06-10 Remove stray editor workspace file; track 2-section foundation run config
    pick_place_2section.yaml is the config behind the warm-start model the
    active stacking run was initialized from; its only other copy lives in
    git-ignored rex_results/. Committed unmodified for provenance.
    Also deleted locally (untracked dead scripts): scratch_quat.py,
    visualize_model.py (hardcoded stale path), MUJOCO_LOG.TXT.
2026-06-10 Hand control: dt-aware One Euro filtering, slew limit, stale-camera gate
    Replaces the frame-rate-dependent conditioning in the teleop loop with the
    dt-aware utilities from control/smoothing.py:
    - Cursor/baseline/yaw: One Euro filter (adaptive — heavy smoothing at rest
    kills MediaPipe jitter, light smoothing in motion keeps it direct).
    Legacy fixed-alpha EMA kept behind --filter ema as the A/B baseline.
    - Tendon rate cap: per-frame 0.03 clip -> SlewRateLimiter at 1.8 units/s
    (identical at the 60 fps target, correct at any actual frame rate).
    - Gestures: pinch/flat-palm frame counters -> time-based HoldToTrigger;
    filter state reset on flat-palm neutral, 'c' recalibrate, 'r' reset.
    -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
2026-06-10 Evaluation: headless diagnostic rollout tool for pick-place policies
    First module of the evaluation package (separate from training outputs):
    loads a checkpoint + vecnormalize stats, rebuilds the env at FULL
    curriculum phase, runs N deterministic episodes, and reports grasp /
    lift / carry / place behaviour metrics as JSON, with optional mp4
    rendering. Outputs go to git-ignored eval_results/.
    Used to diagnose the interrupted Stage B stacking run: policy lifts but
    never transports (0/20 places, closest approach 0.147 m vs 0.05 m
    threshold) while a random-action probe reaches the target slot to
    within 1.4 mm - task feasible, transport reward gradient too weak.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
2026-06-10 Record stacking config exactly as used by the interrupted 8M run
    Committing pre-fix provenance before reward changes land.
    [pick_place_stack.yaml]
2026-06-10 Fix stacking reward dead zone + metric defects; tune entropy for retrain
    Diagnosis (8M-step run, 0% place): once grasped, tip_to_obj ~ 0 flattens
    the reach term and nothing pulls the tip toward the slot — the only
    signal was object_progress worth +0.48 total for the 0.16 m transport,
    so PPO converged to lift-and-hover while std collapsed 0.81 -> 0.16.
    A random-action probe reached the slot to within 1.4 mm (task feasible).
    Fixes:
    - carry_reach_reward_scale (new, default 0 = old behaviour): while
    grasped, reward -= scale * tip_to_place. The carry-phase analog of
    the reach term; set to 1.0 in the stack config.
    - Lift baseline = spawn height, not table rest: the top of a 2-stack
    spawne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
    [pick_place_stack.yaml]
2026-06-10 Grasp/place accuracy mode: contact-only grasping + release-and-settle placement
    The legacy mechanics undermined trust in reported success: a 'grasp'
    latched on mere 3.5 cm proximity (no contact), and stacking 'placement'
    teleported the carried cube onto the slot from 5 cm away. Both are now
    config-gated with legacy defaults:
    - grasp_requires_contact (stack: true): only force-bearing tip/object
    contact latches a grasp; proximity alone is shaping signal, not a grasp.
    - place_mode 'release' (stack) vs legacy 'snap': the grasp opens above
    the slot and physics settles the cube; placement counts only if it
    rests within place_distance_threshold of the canonical slot after
    place_settle_step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
    [pick_place_stack.yaml]
2026-06-10 Run-3 reward design: holding pays, transport potential-based, carry penalty off
    Run-2 post-mortem (12M steps, completed): with contact-gated grasping the
    absolute carry penalty made touching the cube a net-negative event for a
    policy that cannot yet place (-0.16/step while grasped vs +5 once), so it
    learned contact avoidance — grasp rate 10% -> 0% in the first 1M steps,
    rollout of the best checkpoint confirms 0/20 grasps. With gradients gone,
    entropy inflated std 0.16 -> 544 (the known blowup mode).
    Lesson encoded in config comments: avoidable state + absolute in-state
    penalty = state avoidance.
    - grasp_hold_bonus (new, default 0; stack 0.15/step): holding beats the
    ~0.11/step max prox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
    [pick_place_stack.yaml]
2026-06-11 Run-4 config: hybrid grasp trigger restored, proximity bonus capped below hold
    Oracle probe (300 random-action episodes each):
    - Contact-only grasping is undiscoverable: force-bearing contact in 2/300
    episodes, latch in 1/300 (0.3%). Runs 2 & 3 (12M steps each) both
    collapsed to 0% grasping under grasp_requires_contact: true. Since the
    carry is assisted regardless, the trigger's realism was cosmetic.
    - Release-and-settle placement is learnable: 12/300 random carries
    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
2026-06-11 Voice control mode: scene registry, scripted primitives, no-LLM sim runner
    Third control mode (voice) now works end-to-end in simulation with zero
    LLM/GPU requirements — rule-based intent parsing drives scripted physics
    primitives:
    - perception/scene_objects.py: discover obj_* bodies from the loaded
    model with color (name hint / material / rgba), shape, size. Replaces
    hardcoded body lists; 'pick up the red cube' resolves per-scene.
    - control/sim_primitives.py: SimArm feedback-positioned primitives
    (move/grasp/carry/place/stack) + SimIntentExecutor. Controller design
    is measurement-driven (documented in-module): polar cursor control
    with per-scene azimuth calibration (the cursor-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
2026-06-11 Fix run-4 place blocker: no re-grasp during settle; carry clear of tip sphere
    Run-4 autopsy (2.8M steps, stopped): grasping healthy at 49-56% but place
    stuck at 0%. Two structural defects:
    1. With the hybrid (proximity) trigger restored, the tip still hovers
    inside grasp_distance_threshold right after the place release, so the
    cube re-latched within grasp_consecutive_steps and the settle logic
    withdrew every attempt — placing was impossible. The proximity trigger
    is now suppressed for the pending cube while its own attempt settles.
    2. grasp_carry_offset 0.015 put the carried cube's top 3 mm inside the
    tip's 8 mm contact sphere; the per-step assist snap re-created the
    pen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
    [pick_place_stack.yaml]
2026-06-11 Synthetic YOLO dataset generator: auto-labeled renders from the sim scene
    Closes the project's dataset gap (the vision pipeline was code-complete
    but had zero images): renders the pick-and-place scene with randomized
    object subsets/poses/yaw, random arm pose, lighting jitter, and free-
    camera viewpoints, then computes pixel-perfect YOLO labels by projecting
    each object's 3D bounds through the camera. No manual annotation;
    classes derive from the scene-object registry (color_shape, dedup'd for
    repeated colors). Outputs ultralytics-ready images/labels/dataset.yaml.
    Verified: 24-image sample, 138/138 valid boxes, overlay images confirm
    tight alignment.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
2026-06-11 Multimodal control: voice co-pilot in hand teleop + compound voice commands
    Voice grammar (rule-based, still no LLM):
    - Command sequencing: 'take the red cube and put it on top of the purple'
    splits on and/then, re-querying gripper state between segments
    ('drop it and catch it' works).
    - Held-object stacking: 'put it on top of the blue' (target optional).
    - STACK_ALL: 'build a stack with all the cubes' -> tower builder that
    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
2026-06-11 Rollout tool: pin the stack count to the training condition
    With object_curriculum_enabled and no curriculum state passed, the env
    falls back to num_spawned_objects (5 in the stack config) — so every
    diagnostic rollout so far evaluated a 5-object source tower (cube +
    cylinder + bar + cubes) whose top is documented as beyond the arm's
    graspable height. Training runs at the 2-cube level; the behavioral
    verdicts were measured off-distribution. (Caught by eyeballing rendered
    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
2026-06-12 Run-6: anti-farming reward integrity + goal-conditioned randomized targets
    Run-5 verdict (12M complete, verified by corrected rollout + video):
    genuine 90% grasping and deliberate partial transport (cube carried to
    min 0.085 m from the slot) — real skill for the first time — but the
    policy then coils up at its base farming the unbounded hold bonus
    (+0.15/step x 240 ≈ +36/episode; at gamma=0.99 the distant +40 place
    payoff cannot compete with immediate infinite flow).
    Three farm-proofing mechanisms (all config-gated, legacy defaults):
    - grasp_hold_bonus_budget_steps (stack: 60): hold flow ends after the
    per-episode budget — acquisition stays attractive, then transport
    (potential-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
    [pick_place_stack.yaml]
2026-06-12 Run-7: match place tolerance to demonstrated carry precision (3 -> 4.5 cm)
    Run-6 verdict (12M complete): goal-conditioned transport is real — 95%
    grasping, cube carried to 5-6 cm of randomized commanded targets
    (verified by deterministic AND stochastic rollouts of best and final
    checkpoints), 15,953 release attempts and 5,716 physical placements
    during training (36% per attempt). But the 3 cm trigger sat ~2 cm
    inside the policy's positioning precision: snapshot policies hover at
    the line and rarely fire — exploration noise earned the training-time
    placements.
    Run 7 (short, 4M steps, warm-started from run-6 best) widens trigger +
    settle judge to 4.5 cm — inside the demonstrated envelop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
    [pick_place_stack.yaml]
2026-06-12 Demo quality fixes: feel-tested speed/jerk, mic status, spawn ring, pacing
    User feel-testing exposed four real defects:
    1. Hand control jerky + too fast: the tendon rate cap was derived as a
    '60 fps equivalent' (1.8 m/s), but the webcam+MediaPipe loop runs at
    ~15-25 fps on a laptop, allowing ~3x faster per-frame motion than the
    old controller. Now a feel-tuned 0.8 m/s with a --max-rate knob;
    gentler One Euro defaults (min_cutoff 1.0, beta 0.15).
    2. Violent jerk on every grasp: the auto-wrap 'pre-bend' overwrote
    current_ctrl in one frame, bypassing the slew limiter. Removed - the
    snap-carry alone holds the object.
    3. Mic silently dead: SpeechRecognition/PyAudio were missing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
2026-06-12 Production pass on the voice sim: honest stacking, lift-rotate-lower, clean scene
    User screenshot showed 'Stacked the held object on red' while nothing
    was stacked, objects shoved everywhere, and visible shivering. Three
    defects:
    1. Dishonest verdict: stacking reused the 6 cm place-at-location
    tolerance — meaningless on a 2 cm cube. Stacking is now judged by a
    physical on-top check (_is_stacked_on: xy within 1.5 cm of the base
    centre AND resting at stack height after settling). stack/stack_all
    report only what is physically true; a new test asserts the verdict
    always matches the physics ('the demo may fail, but it may not lie').
    2. Plowing: all nine objects were crammed ont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
2026-06-12 M0: spine damping engineering - 10x faster settle on the dev manipulation scene
    Root cause of the 'shaky, unconfident' robot measured and fixed: the
    spiral's ball joints ship with damping 0.05..0.004 - a nearly undamped
    whip that rings >3.5 s after every command, while the motion loop
    re-excites it every ~1.4 s, so it never settles.
    Sweep findings (damping_study.py, step-response protocol):
    - Pure damping increase is the WRONG fix: it converts ringing into slow
    creep (settle 3.7 -> 7.3 s at 30x).
    - Stiffness+damping co-scaling is right: (x8, x3) gives settle 3.69 ->
    0.358 s, residual 0.74 mm -> 0.005 mm, zero overshoot, 12% reach cost
    (beyond x8 the kp=200 servos lose the fight: -32%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
2026-06-12 M1: contact-gated suction gripper - honest physics replaces the magnet
    The tip is a single 8mm sphere: it cannot wrap-grasp. The honest model
    for this morphology is a suction/adhesion end-effector, and the scene
    has shipped inactive weld equalities (grasp_*) for it all along - the
    legacy controllers bypassed them with kinematic hacks.
    SuctionGripper: attach requires REAL solver-measured contact force
    (>=0.02 N) between tip and object; attachment = activating the weld;
    the physics engine carries the payload; detach = weld off + free
    settle. Zero teleports, zero qpos writes, zero xfrc - asserted by test.
    Physics lessons baked in (each was measured the hard way):
    - MuJoCo resolves zero relpos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
2026-06-12 Update scripts for damping study and frame extraction
